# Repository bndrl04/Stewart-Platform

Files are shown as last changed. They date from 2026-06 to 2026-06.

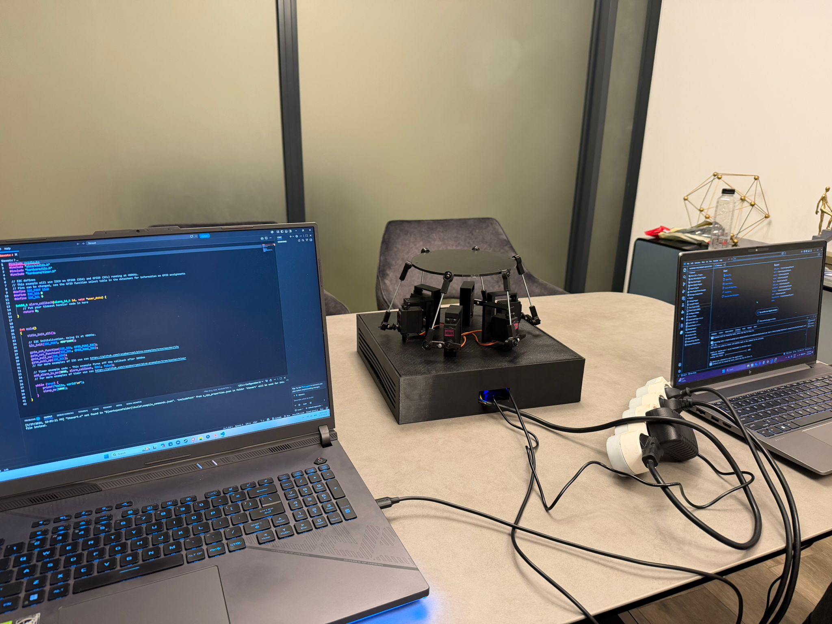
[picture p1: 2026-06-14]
Stewart-Platform-main/Media/Platforma Stewart asamblata (FINAL).jpeg

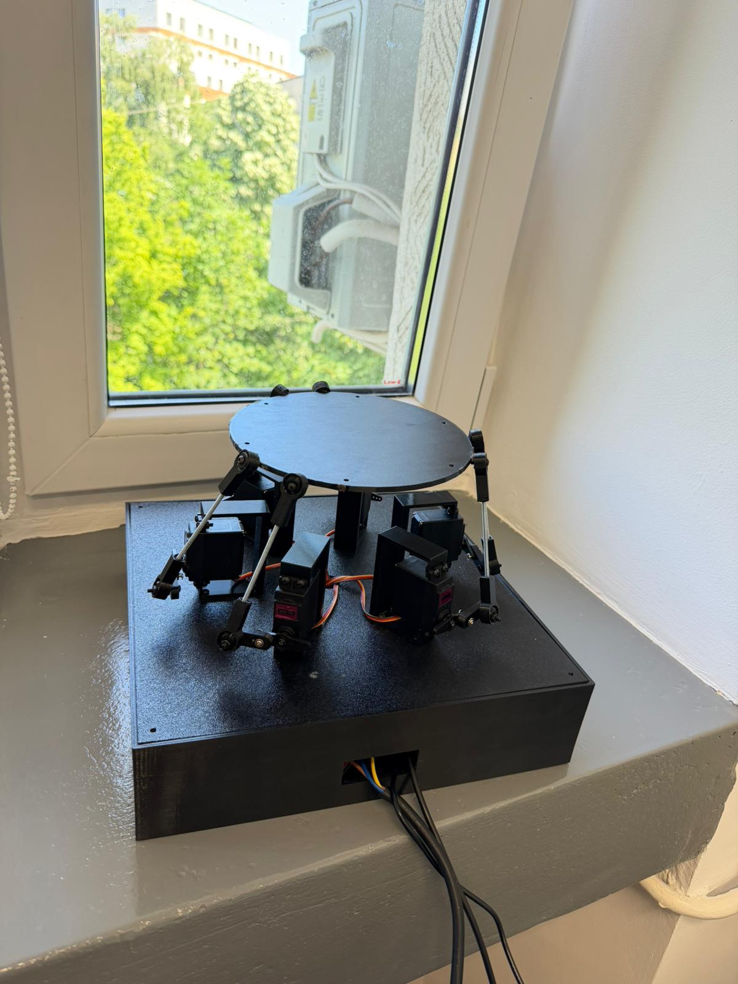
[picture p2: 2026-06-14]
Stewart-Platform-main/Media/Platforma Stewart - Geometrie Rearanjata (FINAL).jpeg

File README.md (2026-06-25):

# Platformă Stewart cu Raspberry Pi Pico

**Student:** *Pohrib George-Rafael*
**Platformă hardware:** Raspberry Pi Pico 2 W

---

## 1. Descrierea proiectului

Proiectul constă în construirea unei platforme Stewart (hexapod) cu structură printată 3D și tăiată manual, controlată de un Raspberry Pi Pico. Utilizatorul transmite comenzi de poziție și orientare prin interfața wireless, iar sistemul calculează în timp real cinematica inversă și controlează simultan șase servomotoare MG996R pentru a poziționa platforma superioară în spațiu. Sistemul oferă șase grade de libertate complete: translație pe axele X, Y, Z și rotație *pitch*, *roll*, *yaw*.

## 2. Cerințe funcționale

### 2.1 Control al poziției și orientării

Sistemul acceptă comenzi de poziție *(x, y, z)* și orientare *(pitch, roll, yaw)* și calculează automat unghiurile necesare pentru fiecare dintre cele șase servomotoare prin algoritmi de cinematică inversă. Mișcarea rezultată trebuie să fie fluidă și sincronizată între toate servomotoarele.

### 2.2 Generarea semnalelor PWM pentru servomotoare

Fiecare dintre cele șase servomotoare MG996R este controlat printr-un semnal PWM independent, generat de pinii hardware PWM ai Pico. Rezoluția și frecvența semnalului (50 Hz) trebuie să asigure poziționare precisă și stabilă a platformei.

### 2.3 Afișarea stării în timp real

Sistemul comunică starea curentă conform următoarelor mesaje:

- `Initializing...` — la pornire și calibrare;
- `Ready` și poziția curentă — în așteptarea comenzilor;
- `Moving...` — în timpul execuției unei mișcări;
- `Error: <detaliu>` — la detectarea unei erori de inițializare sau limită depășită.

### 2.4 Calibrare și poziție neutră

La pornire, sistemul aduce automat toate servomotoarele în poziția neutră (platformă orizontală, la înălțime medie), verificând răspunsul corect al fiecărui actuator. Eșecul unui servomotor determină semnalizarea erorii și întreruperea procedurii de inițializare.

### 2.5 Limitarea spațiului de lucru

Fiecare comandă de poziție este limitata conform unor parametri stabiliti in prealabil in cod, pentru a nu lasa utilizatorul sa scoata din spatiul de lucru atat platforma, cat si vreunul dintre servomotoare.
### 2.6 Mișcare interpolată

Deplasările între două poziții succesive sunt interpolate în pași mici, evitându-se mișcările bruște care ar putea deteriora mecanismul sau suprasolicita servomotoarele.

### 2.7 Blocare de urgență

Sistemul permite transmiterea unei comenzi de oprire imediată, care readuce platforma în poziția neutră și suspendă procesarea oricăror alte comenzi până la o resetare manuală.

## 3. Cerințe non-funcționale

### 3.1 Fiabilitate mecanică

Structura printată 3D trebuie să reziste forțelor generate de cele șase servomotoare MG996R în regim normal de funcționare. Articulațiile sferice se verifică periodic pentru semne de uzură, iar toate conexiunile electrice sunt securizate împotriva deconectării în timpul mișcării.

### 3.2 Precizia de poziționare

Eroarea de poziționare a platformei superioare nu trebuie să depășească ±2 mm pe componenta de translație și ±2° pe componenta de rotație, în condiții de încărcare normală.

### 3.3 Consum energetic

Alimentarea servomotoarelor se realizează separat de cea a Pico (sursă dedicată 5 V / 3 A), evitându-se solicitarea pinilor microcontrollerului. În repaus, când nicio comandă nu este procesată, servomotoarele sunt dezactivate pentru reducerea consumului și a încălzirii.

### 3.4 Latența de răspuns

Timpul scurs între primirea unei comenzi wireless și începutul efectiv al mișcării nu trebuie să depășească 100 ms, în condiții normale de rețea locală.

### 3.5 Extensibilitate

Arhitectura software permite adăugarea de moduri noi de operare (urmărire de traiectorie, mod demonstrație, control prin IMU) fără restructurarea completă a codului existent. Parametrii geometrici ai platformei (raze, lungimi de tije) sunt configurabili dintr-un singur fișier de configurare.

Momentan se lucreaza la o aplicatie mobile pentru control giroscopic.

### 3.6 Toleranța la erori de comunicație

În cazul întreruperii conexiunii wireless, platforma revine automat în poziția neutră după un *timeout* configurabil și rămâne stabilă până la restabilirea legăturii.

---

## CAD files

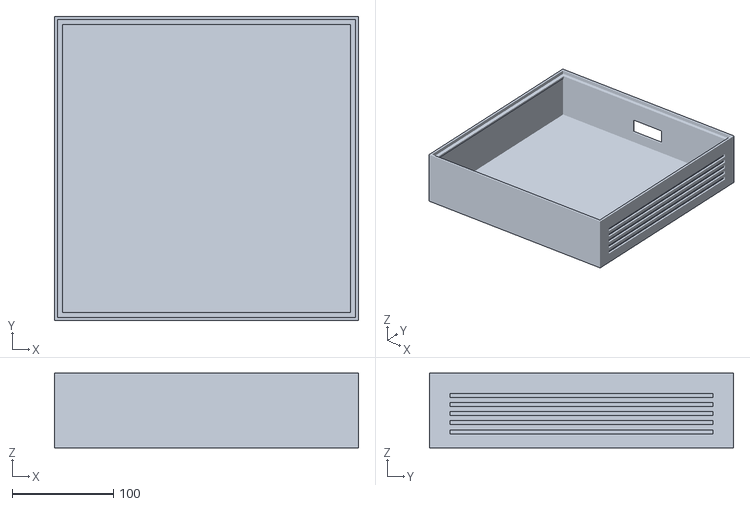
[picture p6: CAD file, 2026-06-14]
Stewart-Platform-main/Schite 3D/Cutie.stl
300.0 x 300.0 x 74.0

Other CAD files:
Stewart-Platform-main/Schite 3D/capac_cutie.dwg
Stewart-Platform-main/Schite 3D/manivela.dwg
Stewart-Platform-main/Schite 3D/bila_rod_end.dwg
Stewart-Platform-main/Schite 3D/suport_motor_final.dwg
Stewart-Platform-main/Schite 3D/platforma.dwg
Stewart-Platform-main/Schite 3D/cupa_rod_end.dwg
Stewart-Platform-main/Schite 3D/Suport_Motor.dwg
Stewart-Platform-main/Schite 3D/Cutie.dwg

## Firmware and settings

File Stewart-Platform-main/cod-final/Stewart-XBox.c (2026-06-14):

#include <stdio.h>
#include <string.h>
#include <stdlib.h>
#include <math.h>
#include "pico/stdlib.h"
#include "hardware/i2c.h"
#include "hardware/timer.h"

#include "pca9685.h"
#include "stewart_kinematics.h"

// ---- Hardware config ----
#define I2C_PORT     i2c0
#define I2C_SDA_PIN  4
#define I2C_SCL_PIN  5
#define I2C_FREQ_HZ  (400 * 1000)

#define PCA9685_ADDR PCA9685_DEFAULT_ADDR
#define SERVO_PWM_HZ 50.0f

// ---- Per-servo calibration ----
// Mechanical offset applied AFTER subtracting the HOME crank angle. Tweak each
// value after physical calibration (palonier mount tolerance). Positive value
// rotates the crank further CCW/up at the same logical command.
static const float servo_home_offset_deg[STEWART_NUM_LEGS] = {
    0.0f, 0.0f, 0.0f, +15.0f, 0.0f, 0.0f
};

// Physical wiring sign per servo. Inverts the PWM pulse direction to match how
// the servo is physically mounted (i.e. which way a positive crank delta makes
// the rod end go). In the paired/mirrored config, the mirrored servos in each
// pair end up with opposite physical sign relative to the standard ones.
// Calibrate empirically: after `home`, if `pos 0 0 H0+5` lowers a corner
// instead of raising it, flip the sign for the offending servo.
static const float servo_phys_sign[STEWART_NUM_LEGS] = {
    +1.0f, -1.0f, +1.0f, -1.0f, +1.0f, -1.0f
};

// PCA9685 channel assignment for legs 0..5.
static const uint8_t servo_channel[STEWART_NUM_LEGS] = { 0, 1, 2, 3, 4, 5 };

// ---- Motion state ----
typedef struct {
    float x, y, z, roll, pitch, yaw;
} pose_t;

static pose_t pose_current = { 0, 0, STEWART_H0, 0, 0, 0 };
static pose_t pose_target  = { 0, 0, STEWART_H0, 0, 0, 0 };
static volatile bool motion_active = false;

// Linear interpolation step per 10 ms tick. Tuned for responsive Xbox control.
#define STEP_POS_MM_PER_TICK   0.30f   // 30 mm/s
#define STEP_ANG_DEG_PER_TICK  0.60f   // 60 deg/s

// Stream mode: when on, suppresses character echo, "OK" replies and the prompt
// so a host script can push high-rate `rt` commands without log clutter.
static volatile bool stream_mode = false;

// Safety limits for streaming control (conservative). Used by `rt` command only.
#define RT_LIMIT_TRANS_MM       10.0f       // |x|, |y| <= this
#define RT_Z_MIN_MM             (STEWART_H0 - 10.0f)
#define RT_Z_MAX_MM             (STEWART_H0 + 15.0f)
#define RT_LIMIT_ROLL_PITCH_DEG 10.0f
#define RT_LIMIT_YAW_DEG        15.0f

// HOME crank angles, populated at boot from IK.
static float alpha_home[STEWART_NUM_LEGS] = {0};

// Servo override: when non-negative, that servo is being driven directly via
// "servo N angle" and is excluded from IK updates.
static int8_t servo_override_active[STEWART_NUM_LEGS] = { 0, 0, 0, 0, 0, 0 };

// Demo mode flag (cycles through poses).
static bool demo_running = false;
static uint32_t demo_step = 0;
static uint32_t demo_next_ms = 0;

// ---- Helpers ----

static float clampf(float v, float lo, float hi) {
    if (v < lo) return lo;
    if (v > hi) return hi;
    return v;
}

static void apply_pose(const pose_t *p) {
    float crank[STEWART_NUM_LEGS];
    unsigned int unreachable = 0;
    int rc = stewart_ik(p->x, p->y, p->z, p->roll, p->pitch, p->yaw,
                        crank, &unreachable);
    if (rc & STEWART_ERR_UNREACHABLE) {
        printf("WARN: unreachable, mask=0x%02x (legs clamped)\n", unreachable);
    }
    for (int i = 0; i < STEWART_NUM_LEGS; ++i) {
        if (servo_override_active[i]) continue;
        float delta = crank[i] - alpha_home[i];
        float cmd = servo_phys_sign[i] * delta + servo_home_offset_deg[i];
        cmd = clampf(cmd, -90.0f, 90.0f);
        pca9685_set_servo_angle(servo_channel[i], cmd);
    }
}

static bool step_toward(float *cur, float target, float step) {
    float diff = target - *cur;
    if (fabsf(diff) <= step) {
        *cur = target;
        return true;
    }
    *cur += (diff > 0 ? step : -step);
    return false;
}

// 100 Hz motion timer.
static bool motion_tick(repeating_timer_t *t) {
    (void)t;
    if (!motion_active) return true;
    bool d1 = step_toward(&pose_current.x,     pose_target.x,     STEP_POS_MM_PER_TICK);
    bool d2 = step_toward(&pose_current.y,     pose_target.y,     STEP_POS_MM_PER_TICK);
    bool d3 = step_toward(&pose_current.z,     pose_target.z,     STEP_POS_MM_PER_TICK);
    bool d4 = step_toward(&pose_current.roll,  pose_target.roll,  STEP_ANG_DEG_PER_TICK);
    bool d5 = step_toward(&pose_current.pitch, pose_target.pitch, STEP_ANG_DEG_PER_TICK);
    bool d6 = step_toward(&pose_current.yaw,   pose_target.yaw,   STEP_ANG_DEG_PER_TICK);
    apply_pose(&pose_current);
    if (d1 && d2 && d3 && d4 && d5 && d6) motion_active = false;
    return true;
}

// Returns true if the pose was accepted, false if rejected (unreachable target).
// When rejected, neither pose_target nor pose_current changes; the current
// motion (if any) continues to its existing target.
static bool set_target_pose(float x, float y, float z,
                            float roll, float pitch, float yaw) {
    float dummy[STEWART_NUM_LEGS];
    unsigned int unreachable = 0;
    int rc = stewart_ik(x, y, z, roll, pitch, yaw, dummy, &unreachable);
    if (rc & STEWART_ERR_UNREACHABLE) {
        printf("REJECT: target outside workspace, leg mask=0x%02x\n", unreachable);
        return false;
    }
    pose_target.x     = x;
    pose_target.y     = y;
    pose_target.z     = z;
    pose_target.roll  = roll;
    pose_target.pitch = pitch;
    pose_target.yaw   = yaw;
    motion_active = true;
    return true;
}

// ---- Demo sequence ----

typedef struct {
    pose_t pose;
    uint32_t hold_ms;
} demo_step_t;

static const demo_step_t demo_seq[] = {
    {{   0,   0, STEWART_H0,        0,    0,    0 }, 1000 },
    {{   0,   0, STEWART_H0 + 15,   0,    0,    0 }, 1000 },
    {{   0,   0, STEWART_H0 - 15,   0,    0,    0 }, 1000 },
    {{   0,   0, STEWART_H0,       10,    0,    0 }, 1000 },
    {{   0,   0, STEWART_H0,      -10,    0,    0 }, 1000 },
    {{   0,   0, STEWART_H0,        0,   10,    0 }, 1000 },
    {{   0,   0, STEWART_H0,        0,  -10,    0 }, 1000 },
    {{   0,   0, STEWART_H0,        0,    0,   15 }, 1000 },
    {{   0,   0, STEWART_H0,        0,    0,  -15 }, 1000 },
    {{  10,   0, STEWART_H0,        0,    0,    0 }, 1000 },
    {{   0,  10, STEWART_H0,        0,    0,    0 }, 1000 },
    {{   0,   0, STEWART_H0,        0,    0,    0 }, 1000 },
};
#define DEMO_LEN (sizeof(demo_seq) / sizeof(demo_seq[0]))

static void demo_advance(void) {
    if (!demo_running) return;
    if (!motion_active && (int32_t)(to_ms_since_boot(get_absolute_time()) - demo_next_ms) >= 0) {
        const demo_step_t *s = &demo_seq[demo_step];
        set_target_pose(s->pose.x, s->pose.y, s->pose.z,
                        s->pose.roll, s->pose.pitch, s->pose.yaw);
        demo_next_ms = to_ms_since_boot(get_absolute_time()) + s->hold_ms;
        demo_step = (demo_step + 1) % DEMO_LEN;
    }
}

// ---- Command parser ----

static void print_help(void) {
    printf(
        "Commands:\n"
        "  home              -> move to HOME (z=%.1f)\n"
        "  pos x y z         -> set translation, keep rotation\n"
        "  rot rx ry rz      -> set rotation (roll pitch yaw, deg), keep translation\n"
        "  pose x y z rx ry rz -> set full pose\n"
        "  servo N angle     -> drive servo N (0..5) to angle directly (-90..90)\n"
        "  release           -> release all servo overrides (resume IK)\n"
        "  demo              -> start demo sequence\n"
        "  stop              -> stop motion / demo\n"
        "  status            -> print current and target pose\n"
        "  stream on|off     -> toggle silent mode (no echo/prompt) for host streaming\n"
        "  rt x y z rx ry rz -> silent realtime pose update, clamped to safe limits\n"
        "  help              -> this list\n",
        STEWART_H0);
}

static void cmd_home(void) {
    demo_running = false;
    for (int i = 0; i < STEWART_NUM_LEGS; ++i) servo_override_active[i] = 0;
    set_target_pose(0, 0, STEWART_H0, 0, 0, 0);
    printf("OK home\n");
}

static void cmd_status(void) {
    printf("cur:  x=%.2f y=%.2f z=%.2f rx=%.2f ry=%.2f rz=%.2f\n",
           pose_current.x, pose_current.y, pose_current.z,
           pose_current.roll, pose_current.pitch, pose_current.yaw);
    printf("tgt:  x=%.2f y=%.2f z=%.2f rx=%.2f ry=%.2f rz=%.2f\n",
           pose_target.x, pose_target.y, pose_target.z,
           pose_target.roll, pose_target.pitch, pose_target.yaw);
    printf("motion=%d demo=%d\n", motion_active ? 1 : 0, demo_running ? 1 : 0);
}

static void handle_command(char *line) {
    while (*line == ' ' || *line == '\t') ++line;
    if (*line == '\0') return;

    char *tok = strtok(line, " \t\r\n");
    if (!tok) return;

    if (strcmp(tok, "help") == 0) {
        print_help();
    } else if (strcmp(tok, "home") == 0) {
        cmd_home();
    } else if (strcmp(tok, "status") == 0) {
        cmd_status();
    } else if (strcmp(tok, "stop") == 0) {
        motion_active = false;
        demo_running = false;
        pose_target = pose_current;
        printf("OK stop\n");
    } else if (strcmp(tok, "demo") == 0) {
        demo_running = true;
        demo_step = 0;
        demo_next_ms = to_ms_since_boot(get_absolute_time());
        for (int i = 0; i < STEWART_NUM_LEGS; ++i) servo_override_active[i] = 0;
        printf("OK demo\n");
    } else if (strcmp(tok, "release") == 0) {
        for (int i = 0; i < STEWART_NUM_LEGS; ++i) servo_override_active[i] = 0;
        set_target_pose(pose_current.x, pose_current.y, pose_current.z,
                        pose_current.roll, pose_current.pitch, pose_current.yaw);
        printf("OK release\n");
    } else if (strcmp(tok, "pos") == 0) {
        char *sx = strtok(NULL, " \t\r\n");
        char *sy = strtok(NULL, " \t\r\n");
        char *sz = strtok(NULL, " \t\r\n");
        if (!sx || !sy || !sz) { printf("ERR pos needs 3 args\n"); return; }
        if (set_target_pose(strtof(sx, NULL), strtof(sy, NULL), strtof(sz, NULL),
                            pose_target.roll, pose_target.pitch, pose_target.yaw)) {
            printf("OK pos\n");
        }
    } else if (strcmp(tok, "rot") == 0) {
        char *sr = strtok(NULL, " \t\r\n");
        char *sp = strtok(NULL, " \t\r\n");
        char *sy = strtok(NULL, " \t\r\n");
        if (!sr || !sp || !sy) { printf("ERR rot needs 3 args\n"); return; }
        if (set_target_pose(pose_target.x, pose_target.y, pose_target.z,
                            strtof(sr, NULL), strtof(sp, NULL), strtof(sy, NULL))) {
            printf("OK rot\n");
        }
    } else if (strcmp(tok, "pose") == 0) {
        char *args[6];
        for (int i = 0; i < 6; ++i) {
            args[i] = strtok(NULL, " \t\r\n");
            if (!args[i]) { printf("ERR pose needs 6 args\n"); return; }
        }
        if (set_target_pose(strtof(args[0], NULL), strtof(args[1], NULL), strtof(args[2], NULL),
                            strtof(args[3], NULL), strtof(args[4], NULL), strtof(args[5], NULL))) {
            printf("OK pose\n");
        }
    } else if (strcmp(tok, "rt") == 0) {
        // Realtime pose update: silent, clamped, used by host streaming scripts.
        char *args[6];
        for (int i = 0; i < 6; ++i) {
            args[i] = strtok(NULL, " \t\r\n");
            if (!args[i]) return;  // silent fail in stream
        }
        float x  = clampf(strtof(args[0], NULL), -RT_LIMIT_TRANS_MM,      RT_LIMIT_TRANS_MM);
        float y  = clampf(strtof(args[1], NULL), -RT_LIMIT_TRANS_MM,      RT_LIMIT_TRANS_MM);
        float z  = clampf(strtof(args[2], NULL),  RT_Z_MIN_MM,            RT_Z_MAX_MM);
        float rr = clampf(strtof(args[3], NULL), -RT_LIMIT_ROLL_PITCH_DEG, RT_LIMIT_ROLL_PITCH_DEG);
        float rp = clampf(strtof(args[4], NULL), -RT_LIMIT_ROLL_PITCH_DEG, RT_LIMIT_ROLL_PITCH_DEG);
        float ry = clampf(strtof(args[5], NULL), -RT_LIMIT_YAW_DEG,        RT_LIMIT_YAW_DEG);
        // Clear any leftover servo overrides so all 6 follow the IK in streaming.
        for (int i = 0; i < STEWART_NUM_LEGS; ++i) servo_override_active[i] = 0;
        set_target_pose(x, y, z, rr, rp, ry);
        // no OK reply: keep upstream traffic minimal
    } else if (strcmp(tok, "stream") == 0) {
        char *arg = strtok(NULL, " \t\r\n");
        if (arg && strcmp(arg, "on") == 0) {
            stream_mode = true;
            printf("OK stream on\n");
        } else if (arg && strcmp(arg, "off") == 0) {
            stream_mode = false;
            printf("OK stream off\n");
        } else {
            printf("ERR stream needs 'on' or 'off'\n");
        }
    } else if (strcmp(tok, "servo") == 0) {
        char *sn = strtok(NULL, " \t\r\n");
        char *sa = strtok(NULL, " \t\r\n");
        if (!sn || !sa) { printf("ERR servo needs 2 args\n"); return; }
        int n = atoi(sn);
        float a = strtof(sa, NULL);
        if (n < 0 || n >= STEWART_NUM_LEGS) { printf("ERR servo idx 0..5\n"); return; }
        servo_override_active[n] = 1;
        pca9685_set_servo_angle(servo_channel[n], clampf(servo_phys_sign[n] * a, -90.0f, 90.0f));
        printf("OK servo %d %.2f\n", n, a);
    } else {
        printf("ERR unknown '%s' (try 'help')\n", tok);
    }
}

// ---- Main ----

int main(void) {
    stdio_init_all();

    // Wait briefly for USB CDC to come up so the banner is visible.
    for (int i = 0; i < 30 && !stdio_usb_connected(); ++i) sleep_ms(100);

    i2c_init(I2C_PORT, I2C_FREQ_HZ);
    gpio_set_function(I2C_SDA_PIN, GPIO_FUNC_I2C);
    gpio_set_function(I2C_SCL_PIN, GPIO_FUNC_I2C);
    gpio_pull_up(I2C_SDA_PIN);
    gpio_pull_up(I2C_SCL_PIN);

    printf("Stewart Platform 6-RSS (XBox control) booting...\n");

    if (!pca9685_init(I2C_PORT, PCA9685_ADDR)) {
        printf("FATAL: PCA9685 init failed at 0x%02x\n", PCA9685_ADDR);
        while (1) tight_loop_contents();
    }
    if (!pca9685_set_pwm_freq(SERVO_PWM_HZ)) {
        printf("FATAL: PCA9685 freq set failed\n");
        while (1) tight_loop_contents();
    }

    int rc = stewart_home_angles(alpha_home);
    if (rc != STEWART_OK) {
        printf("WARN: HOME IK status=0x%02x (geometry off?)\n", rc);
    }
    printf("HOME crank angles (deg): ");
    for (int i = 0; i < STEWART_NUM_LEGS; ++i) printf("%.2f ", alpha_home[i]);
    printf("\n");

    // Park at HOME (no smooth ramp yet, no current pose known).
    apply_pose(&pose_current);

    repeating_timer_t timer;
    add_repeating_timer_ms(-10, motion_tick, NULL, &timer);

    print_help();
    printf("> ");
    fflush(stdout);

    char line[128];
    size_t len = 0;
    while (true) {
        int c = getchar_timeout_us(0);
        if (c == PICO_ERROR_TIMEOUT) {
            demo_advance();
            sleep_ms(2);
            continue;
        }
        if (c == '\r' || c == '\n') {
            if (len > 0) {
                line[len] = '\0';
                if (!stream_mode) putchar('\n');
                handle_command(line);
                len = 0;
                if (!stream_mode) {
                    printf("> ");
                    fflush(stdout);
                }
            }
        } else if (c == 0x08 || c == 0x7F) {
            if (len > 0) {
                --len;
                if (!stream_mode) { printf("\b \b"); fflush(stdout); }
            }
        } else if (len < sizeof(line) - 1 && c >= 0x20 && c < 0x7F) {
            line[len++] = (char)c;
            if (!stream_mode) { putchar(c); fflush(stdout); }
        }
    }
}

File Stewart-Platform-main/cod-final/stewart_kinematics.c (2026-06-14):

#include "stewart_kinematics.h"
#include <math.h>

#ifndef M_PI
#define M_PI 3.14159265358979323846f
#endif

#define DEG2RAD(d) ((d) * (M_PI / 180.0f))
#define RAD2DEG(r) ((r) * (180.0f / M_PI))

// Base servo-axis angles (deg) on the lid circle, CCW from +X.
static const float phi_base_deg[STEWART_NUM_LEGS] = {
    0.0f, 60.0f, 120.0f, 180.0f, 240.0f, 300.0f
};

// Platform joint angles (deg), CCW from +X, in the platform's own frame.
// Paired config: the 6 joints are grouped around 3 bisectors (30, 150, 270),
// each pair separated by 2*9.17 = 18.34 deg. This pulls neighboring legs closer
// so the mirrored cranks don't collide.
static const float phi_plat_deg[STEWART_NUM_LEGS] = {
    30.0f  -  9.17f, 30.0f  +  9.17f,   // pair 1 -> servos S0, S1
    150.0f -  9.17f, 150.0f +  9.17f,   // pair 2 -> servos S2, S3
    270.0f -  9.17f, 270.0f +  9.17f    // pair 3 -> servos S4, S5
};

// Crank rotation sense per servo. +1 = CCW tangential (standard), -1 = CW
// (mirrored). Paired config has the second servo of each pair mirrored so the
// two cranks in a pair "look toward each other" instead of both going CCW.
static const float servo_sens[STEWART_NUM_LEGS] = {
    +1.0f, -1.0f, +1.0f, -1.0f, +1.0f, -1.0f
};

// Rotation matrix R = Rz(yaw) * Ry(pitch) * Rx(roll), applied to a point in
// the platform frame to bring it into the world frame.
static void rot_zyx(float roll, float pitch, float yaw, float R[3][3]) {
    float cr = cosf(roll),  sr = sinf(roll);
    float cp = cosf(pitch), sp = sinf(pitch);
    float cy = cosf(yaw),   sy = sinf(yaw);

    R[0][0] = cy * cp;
    R[0][1] = cy * sp * sr - sy * cr;
    R[0][2] = cy * sp * cr + sy * sr;

    R[1][0] = sy * cp;
    R[1][1] = sy * sp * sr + cy * cr;
    R[1][2] = sy * sp * cr - cy * sr;

    R[2][0] = -sp;
    R[2][1] = cp * sr;
    R[2][2] = cp * cr;
}

int stewart_ik(float x, float y, float z,
               float roll_deg, float pitch_deg, float yaw_deg,
               float crank_deg_out[STEWART_NUM_LEGS],
               unsigned int *unreachable_mask_out) {
    int status = STEWART_OK;
    unsigned int unreachable_mask = 0;

    float R[3][3];
    rot_zyx(DEG2RAD(roll_deg), DEG2RAD(pitch_deg), DEG2RAD(yaw_deg), R);

    for (int i = 0; i < STEWART_NUM_LEGS; ++i) {
        float pb = DEG2RAD(phi_base_deg[i]);
        float pp = DEG2RAD(phi_plat_deg[i]);

        // Base joint (servo axis center) in world frame.
        float Bx = STEWART_RB * cosf(pb);
        float By = STEWART_RB * sinf(pb);
        float Bz = STEWART_ZAX;

        // Platform joint in the platform's local frame, then rotated + translated.
        float plx = STEWART_RP * cosf(pp);
        float ply = STEWART_RP * sinf(pp);
        float plz = 0.0f;

        float Px = R[0][0]*plx + R[0][1]*ply + R[0][2]*plz + x;
        float Py = R[1][0]*plx + R[1][1]*ply + R[1][2]*plz + y;
        float Pz = R[2][0]*plx + R[2][1]*ply + R[2][2]*plz + z;

        // L = P - B, expressed in the servo's local frame (radial, tangential, z).
        float Lx = Px - Bx, Ly = Py - By, Lz = Pz - Bz;
        // Radial unit vector points outward; tangential is CCW (same sense for all 6).
        float ur_x = cosf(pb),  ur_y = sinf(pb);
        float ut_x = -sinf(pb), ut_y = cosf(pb);
        float Lr = Lx * ur_x + Ly * ur_y;
        float Lt = Lx * ut_x + Ly * ut_y;
        // Lz unchanged.

        // The crank end relative to B is (radial=0, tangential=sens*La*cos(a),
        // z=La*sin(a)), where sens = +1 for CCW-mounted cranks and -1 for the
        // mirrored ones in a pair. Constraint |L - crank_end|^2 = Ls^2 gives:
        //   A*cos(a) + B*sin(a) = C
        // with A = 2*La*sens*Lt, B = 2*La*Lz, C = |L|^2 + La^2 - Ls^2.
        float A = 2.0f * STEWART_LA * servo_sens[i] * Lt;
        float B = 2.0f * STEWART_LA * Lz;
        float Lsq = Lr*Lr + Lt*Lt + Lz*Lz;
        float C = Lsq + STEWART_LA*STEWART_LA - STEWART_LS*STEWART_LS;

        float Rmag = sqrtf(A*A + B*B);
        float alpha_deg;
        if (Rmag < 1e-6f) {
            // Degenerate; B and Lt and Lz both ~0. Treat as unreachable.
            alpha_deg = 0.0f;
            unreachable_mask |= (1u << i);
            status |= STEWART_ERR_UNREACHABLE;
        } else {
            float ratio = C / Rmag;
            if (ratio > 1.0f)  { ratio = 1.0f;  unreachable_mask |= (1u << i); status |= STEWART_ERR_UNREACHABLE; }
            if (ratio < -1.0f) { ratio = -1.0f; unreachable_mask |= (1u << i); status |= STEWART_ERR_UNREACHABLE; }
            // Two solutions: alpha = atan2(B, A) +/- acos(C/R). The "elbow up"
            // solution (rod end above servo, radial leg pulled inward) is the
            // physical one; with our sign convention that is the minus branch.
            float alpha = atan2f(B, A) - acosf(ratio);
            alpha_deg = RAD2DEG(alpha);
        }

        // Clamp to mechanical servo travel.
        if (alpha_deg > 90.0f)  { alpha_deg = 90.0f;  status |= STEWART_ERR_CLAMPED; }
        if (alpha_deg < -90.0f) { alpha_deg = -90.0f; status |= STEWART_ERR_CLAMPED; }

        crank_deg_out[i] = alpha_deg;
    }

    if (unreachable_mask_out) *unreachable_mask_out = unreachable_mask;
    return status;
}

int stewart_home_angles(float crank_deg_out[STEWART_NUM_LEGS]) {
    return stewart_ik(0.0f, 0.0f, STEWART_H0, 0.0f, 0.0f, 0.0f,
                      crank_deg_out, NULL);
}

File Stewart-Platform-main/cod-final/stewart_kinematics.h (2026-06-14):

#ifndef STEWART_KINEMATICS_H
#define STEWART_KINEMATICS_H

#include <stdbool.h>

#ifdef __cplusplus
extern "C" {
#endif

// Geometry (mm / deg). Matches the assembled hardware.
#define STEWART_RB     100.0f  // base servo-axis circle radius
#define STEWART_RP      80.0f  // platform joint circle radius
#define STEWART_LA      30.0f  // crank arm length (servo spline to rod end)
#define STEWART_LS     106.3f  // connecting rod length (ball center to ball center)
#define STEWART_H0     125.0f  // HOME platform height above the lid (paired config)
#define STEWART_ZAX     21.75f // servo-axis height above the lid

#define STEWART_NUM_LEGS 6

// Status flags for stewart_ik (bitmask).
#define STEWART_OK              0
#define STEWART_ERR_UNREACHABLE 0x01  // at least one leg was clamped (out of range)
#define STEWART_ERR_CLAMPED     0x02  // crank angle was clamped to +-90 deg

// Inverse kinematics for a 6-RSS Stewart platform.
//
//   x, y, z      : translation of the platform center, mm. z is the height above
//                  the lid; HOME is x=0, y=0, z=STEWART_H0.
//   roll, pitch, yaw : intrinsic ZYX Euler angles in degrees (roll about X,
//                  pitch about Y, yaw about Z).
//   crank_deg_out: array of 6 absolute crank angles (deg). 0 deg = crank lying
//                  horizontally in the leg's tangential direction (CCW for legs
//                  with servo_sens=+1, CW for legs with servo_sens=-1, i.e. the
//                  mirrored half in the paired config); +90 deg = rod end up.
//   unreachable_mask_out: optional, may be NULL. Bit i set if leg i was clamped.
//
// Returns a bitmask of STEWART_ERR_* flags (0 == STEWART_OK).
int stewart_ik(float x, float y, float z,
               float roll_deg, float pitch_deg, float yaw_deg,
               float crank_deg_out[STEWART_NUM_LEGS],
               unsigned int *unreachable_mask_out);

// Convenience: compute the HOME crank angles (call at boot).
int stewart_home_angles(float crank_deg_out[STEWART_NUM_LEGS]);

#ifdef __cplusplus
}
#endif

#endif

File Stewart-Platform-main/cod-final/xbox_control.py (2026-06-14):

"""
Xbox controller -> Stewart platform (USB serial).

Reads an Xbox 360/One/Series controller via pygame and streams `rt` commands
to the Pico over USB serial at ~50 Hz.

Mapping
-------
  Left stick X    -> roll  (deg)
  Left stick Y    -> pitch (deg, inverted: stick up = pitch forward)
  Right stick X   -> yaw   (deg)
  LT trigger      -> lower Z (toward Z_MIN)
  RT trigger      -> raise Z (toward Z_MAX)
  D-pad           -> X / Y translation (mm)
  A button        -> home (send `home` once)
  B button        -> quit (returns to home, sends `stream off`, exits)
  Start button    -> emergency stop (sends `stop`)

Requirements
------------
  pip install pygame pyserial
"""

import os
import sys
import time
import argparse

import pygame
import serial

# Enable ANSI escape sequences on legacy Windows cmd.exe (no-op on modern terminals).
if os.name == "nt":
    os.system("")

# ----- Tunables (match Pico-side RT_LIMIT_* in Stewart.c) -----
Z_HOME            = 125.0
Z_MIN             = 115.0
Z_MAX             = 140.0
LIMIT_TRANS_MM    = 10.0
LIMIT_ROLL_PITCH  = 10.0
LIMIT_YAW         = 15.0

STICK_DEADZONE    = 0.12       # ignore tiny stick noise
TRIGGER_DEADZONE  = 0.05
LOOP_HZ           = 50         # send rate

# Xbox controller axis layout on Windows via pygame's default driver:
#   axis 0 = LSX, axis 1 = LSY, axis 2 = LT, axis 3 = RSX, axis 4 = RSY, axis 5 = RT
# Note: triggers are normalized to [-1, +1] by pygame; 0 means halfway.
AXIS_LSX, AXIS_LSY = 0, 1
AXIS_RSX, AXIS_RSY = 3, 4
AXIS_LT,  AXIS_RT  = 2, 5

BTN_A, BTN_B, BTN_X, BTN_Y = 0, 1, 2, 3
BTN_LB, BTN_RB             = 4, 5
BTN_BACK, BTN_START        = 6, 7


def apply_deadzone(v, dz):
    if abs(v) < dz:
        return 0.0
    # rescale so output is 0 at edge of deadzone, +/-1 at full deflection
    s = (abs(v) - dz) / (1.0 - dz)
    return s if v > 0 else -s


def trigger_to_unit(raw):
    """pygame reports triggers in [-1, +1] where -1 = released, +1 = pressed."""
    v = (raw + 1.0) * 0.5  # -> [0, 1]
    return v if v > TRIGGER_DEADZONE else 0.0


def open_serial(port, baud=115200):
    s = serial.Serial(port, baud, timeout=0.1, write_timeout=0.5)
    # Give the Pico a moment to settle / drain any stale stdin.
    time.sleep(0.5)
    s.reset_input_buffer()
    return s


def send(ser, line, verbose=False):
    data = (line + "\n").encode("ascii")
    ser.write(data)
    if verbose:
        print(f">>> {line}")


# ANSI escape to clear from cursor to end of line (works on Win10+ terminals).
_CLR_EOL = "\033[K"


def _emit_status(state, x, y, z, roll, pitch, yaw):
    """Overwrite a single status line in-place (state + current pose)."""
    line = (f"\r{state:<13s} "
            f"x={x:+6.2f} y={y:+6.2f} z={z:6.2f} "
            f"roll={roll:+6.2f} pitch={pitch:+6.2f} yaw={yaw:+6.2f}"
            f"{_CLR_EOL}")
    sys.stdout.write(line)
    sys.stdout.flush()


def _emit_error(msg):
    """Print an error on its own line without disturbing the status overwrite."""
    sys.stdout.write(f"\rError: {msg}{_CLR_EOL}\n")
    sys.stdout.flush()


def main():
    ap = argparse.ArgumentParser(description="Xbox -> Stewart platform bridge")
    ap.add_argument("--port", default="COM4", help="Serial port (default COM4)")
    ap.add_argument("--baud", type=int, default=115200)
    ap.add_argument("--verbose", action="store_true", help="print every command")
    args = ap.parse_args()

    print("Initializing... opening serial")
    try:
        ser = open_serial(args.port, args.baud)
    except Exception as e:
        _emit_error(f"cannot open {args.port}: {e}")
        sys.exit(1)

    print("Initializing... starting pygame / detecting controller")
    pygame.init()
    pygame.joystick.init()
    if pygame.joystick.get_count() == 0:
        _emit_error("no joystick/controller detected. Plug in the Xbox controller and retry.")
        sys.exit(1)
    js = pygame.joystick.Joystick(0)
    js.init()
    print(f"Initializing... controller = {js.get_name()} "
          f"({js.get_numaxes()} axes, {js.get_numbuttons()} buttons)")

    # Reset Pico to a known state and enter stream mode.
    print("Initializing... calibrating Stewart (home + stream on)")
    try:
        send(ser, "release")
        send(ser, "home")
        time.sleep(0.5)
        send(ser, "stream on")
        time.sleep(0.1)
    except Exception as e:
        _emit_error(f"serial write failed during init: {e}")
        sys.exit(1)

    print("Bindings: LStick=roll/pitch  RStick X=yaw  LT/RT=z  D-pad=x/y  "
          "A=home  Start=stop  B=quit\n")

    period = 1.0 / LOOP_HZ
    # State tracking: 'Moving...' while sticks are deflected, 'Ready' when at rest.
    last_state = None
    last_pose = (0.0, 0.0, Z_HOME, 0.0, 0.0, 0.0)
    idle_since = time.perf_counter()
    IDLE_HOLD_S = 0.20  # require this much stillness before declaring Ready

    try:
        while True:
            loop_start = time.perf_counter()
            pygame.event.pump()

            # Read axes
            lsx = apply_deadzone(js.get_axis(AXIS_LSX), STICK_DEADZONE)
            lsy = apply_deadzone(js.get_axis(AXIS_LSY), STICK_DEADZONE)
            rsx = apply_deadzone(js.get_axis(AXIS_RSX), STICK_DEADZONE)
            lt  = trigger_to_unit(js.get_axis(AXIS_LT))
            rt  = trigger_to_unit(js.get_axis(AXIS_RT))

            # D-pad (hat) for X/Y translation
            hat_x, hat_y = (0, 0)
            if js.get_numhats() > 0:
                hat_x, hat_y = js.get_hat(0)

            # Buttons
            btn_a     = js.get_button(BTN_A)
            btn_b     = js.get_button(BTN_B)
            btn_start = js.get_button(BTN_START)

            # Map to pose
            roll  = LIMIT_ROLL_PITCH * lsx
            pitch = LIMIT_ROLL_PITCH * (-lsy)   # invert: stick forward = pitch nose-down
            yaw   = LIMIT_YAW        * rsx
            z = Z_HOME + (rt * (Z_MAX - Z_HOME)) - (lt * (Z_HOME - Z_MIN))
            x = LIMIT_TRANS_MM * hat_x
            y = LIMIT_TRANS_MM * hat_y

            # Button actions
            if btn_a:
                try:
                    send(ser, "home", args.verbose)
                except Exception as e:
                    _emit_error(f"serial write failed: {e}")
                    break
                # Force a Ready redraw after home settles.
                sys.stdout.write("\n")
                last_state = None
                time.sleep(0.3)
                continue
            if btn_start:
                try:
                    send(ser, "stop", args.verbose)
                except Exception as e:
                    _emit_error(f"serial write failed: {e}")
                    break
                time.sleep(0.1)
                continue
            if btn_b:
                raise KeyboardInterrupt
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

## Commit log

2026-05-21 test
    cod de test pentru functionalitatea componentelor
2026-06-14 proiect final platforma stewart
    [Cutie.dwg, Cutie.stl, Suport_Motor.dwg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]
2026-06-25 Update README with mobile app development details
    Added information about ongoing mobile application development for gyroscopic control.
